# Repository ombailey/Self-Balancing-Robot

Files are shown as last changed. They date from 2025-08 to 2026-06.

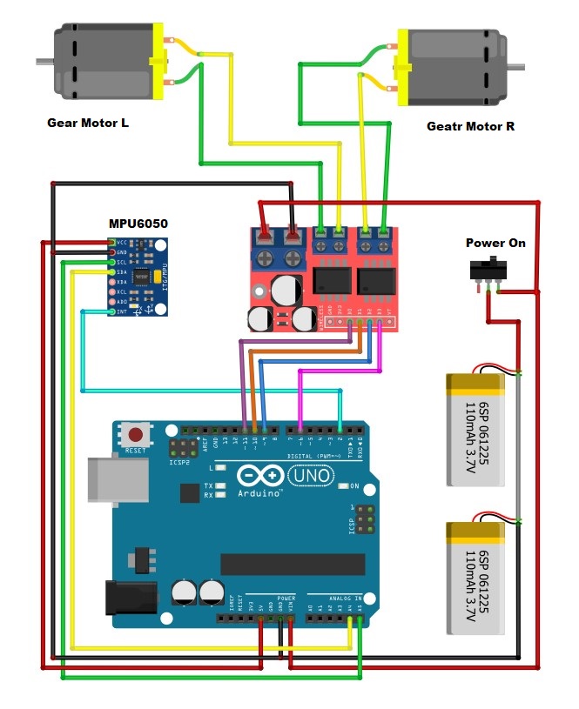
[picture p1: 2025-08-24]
Design/Schematic/0e4da654-2c3c-4273-9591-d0066f8ff958.jpg

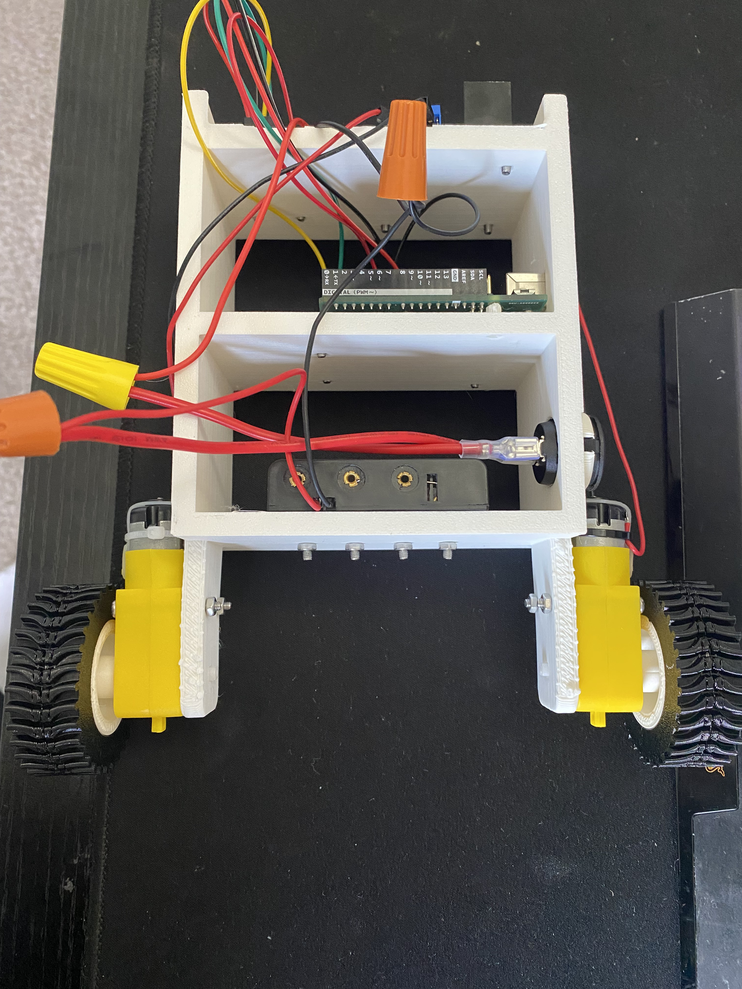
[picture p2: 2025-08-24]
Design/Schematic/SB robot pics/image1.jpeg

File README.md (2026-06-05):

# Self-Balancing Robot

## Overview
This project implements a two-wheeled self-balancing robot using a microcontroller, MPU6050 and PID control. The system models an inverted pendulum and applies state-space control methods to achieve upright stabilization on real hardware.

---

## Features
- Derived nonlinear equations of motion using Lagrangian mechanics
- Linearized state-space model about the upright equilibrium point
- Feedback controller design using pole placement
- Implementation on Arduino-based embedded system
- Complementary filter for real-time angle estimation
- Achieved sustained balancing on physical hardware (>60 seconds)

---

## Hardware
- Arduino microcontroller
- MPU6050
- DC motors
- L298N motor driver
- 3.7 Lithium Batteries (2)

---

## Software
- Embedded C++ (Arduino)
- Python
- Control Toolbox

---

## StatusPython
- Mathematical model derived and validated
- State-space controller designed and implemented
- Complementary filter implemented
- Successfully demonstrated stable balancing for 60+ seconds on repeated trials
- Ongoing improvements to robustness and performance

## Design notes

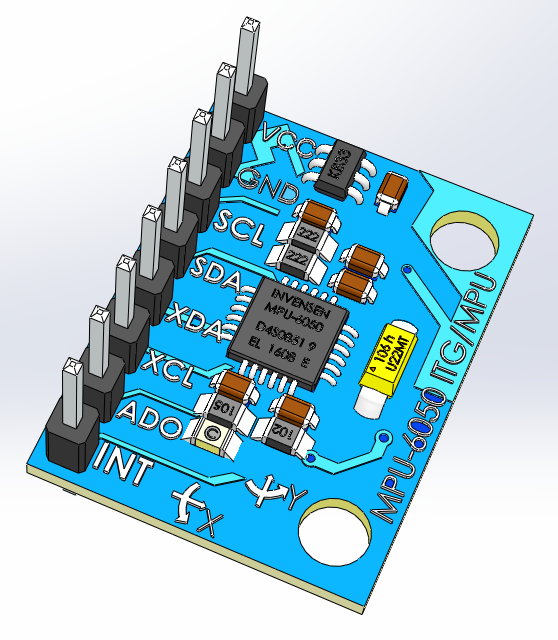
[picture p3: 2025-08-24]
Design/Grabcad/capteur-gyroscopique-analogique-accelerometre-3-axes-mpu-6050-1.snapshot.2/CaptureMPU2.PNG

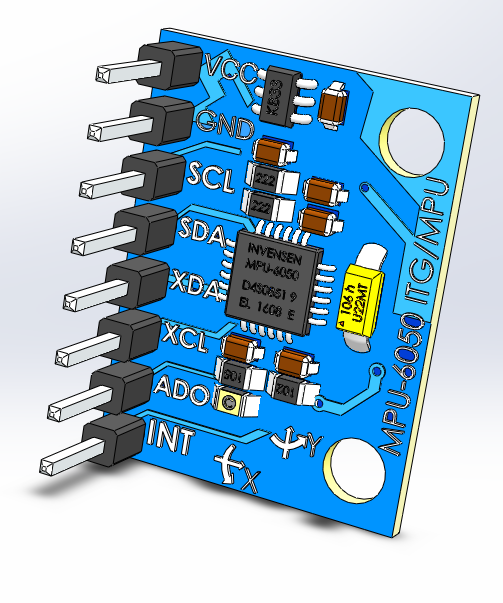
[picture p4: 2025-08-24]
Design/Grabcad/capteur-gyroscopique-analogique-accelerometre-3-axes-mpu-6050-1.snapshot.2/CaptureMPU1.PNG

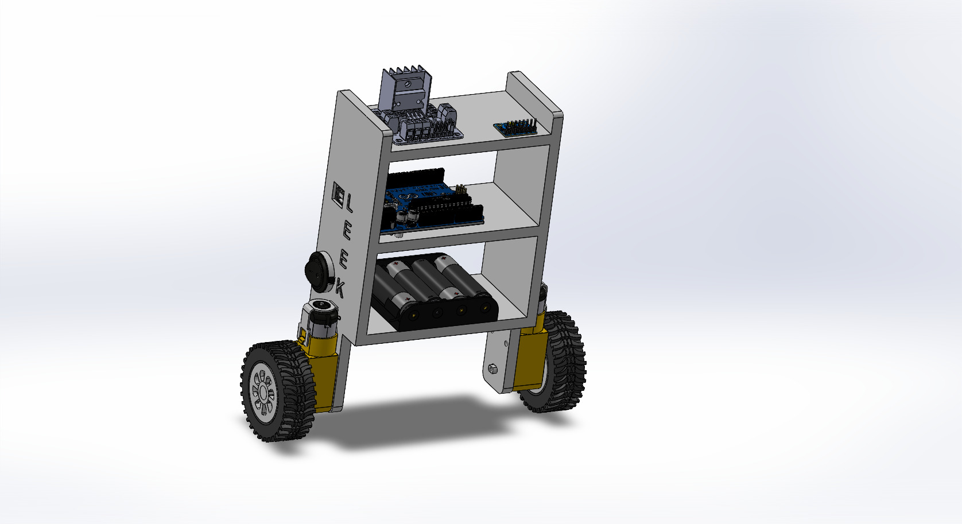
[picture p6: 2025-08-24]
Media/Screenshot3.JPG

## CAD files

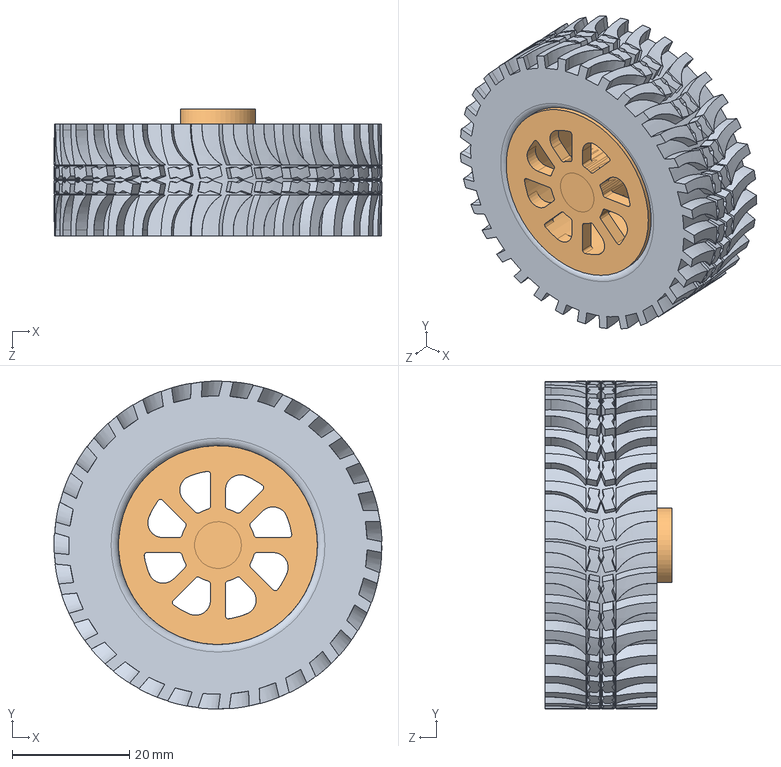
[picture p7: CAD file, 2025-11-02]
Design/CAD files/Big Tread Tire Assembly.SLDASM
55.9 x 55.9 x 21.6 mm
Rims3
Big Tread Tire

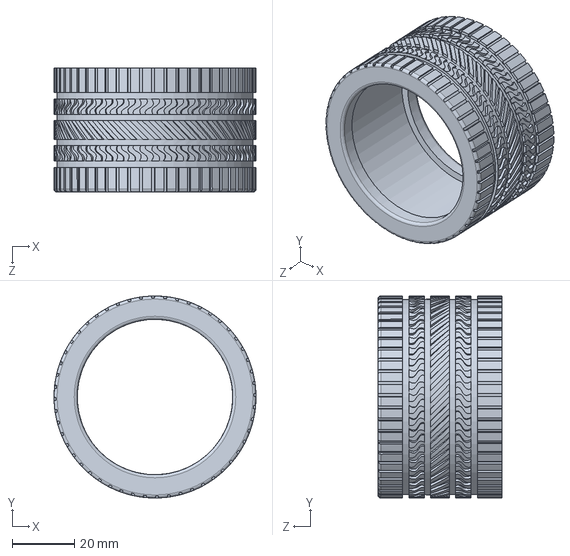
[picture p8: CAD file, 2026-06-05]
Design/CAD files/Tire.SLDPRT
65.0 x 65.0 x 40.0 mm

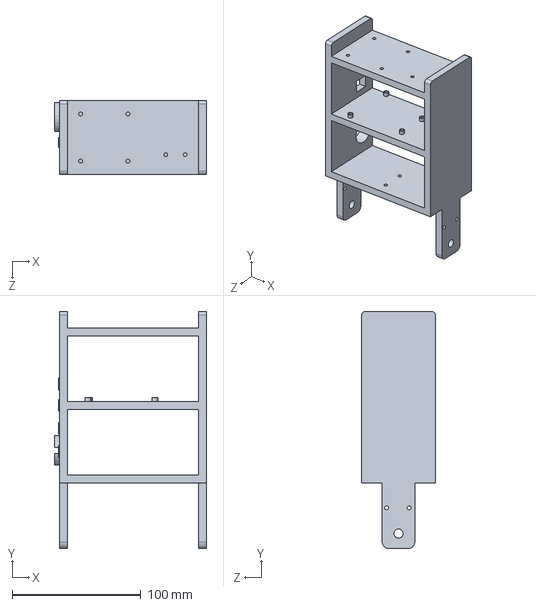
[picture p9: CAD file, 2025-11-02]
Design/frame2.SLDPRT
118.1 x 184.2 x 57.1 mm

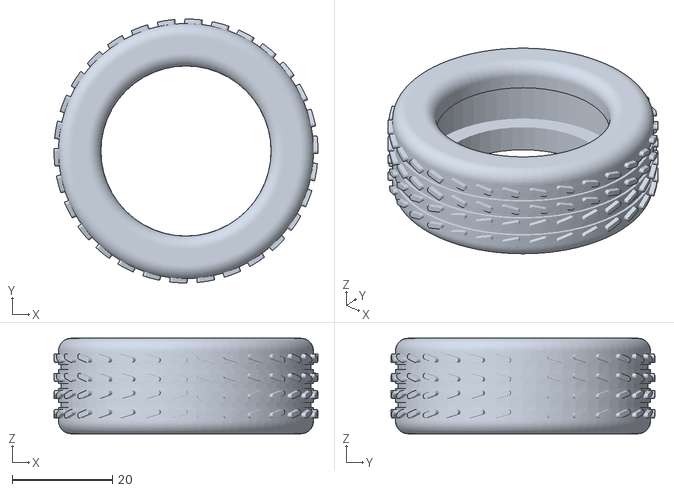
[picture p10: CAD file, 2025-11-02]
Design/STL Files/Tire3.STL
52.6 x 52.6 x 19.1

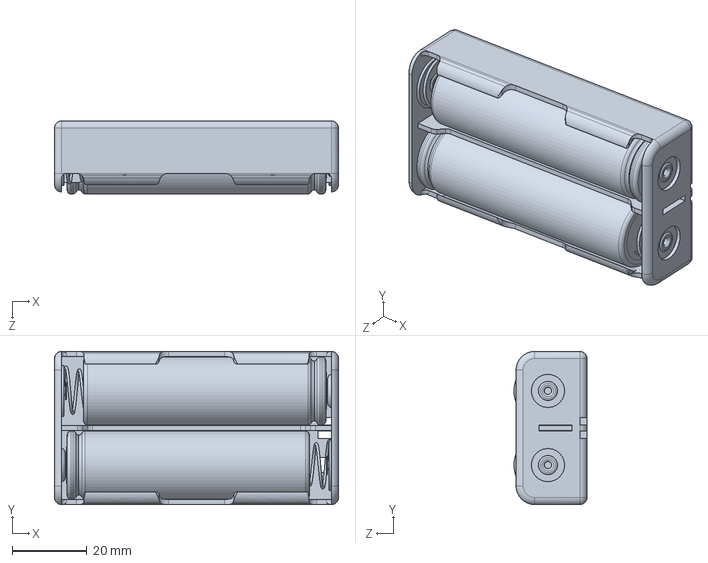
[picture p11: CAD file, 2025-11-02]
Design/BATTERY HOLDER x2 18650.SLDPRT
76.0 x 41.0 x 19.5 mm

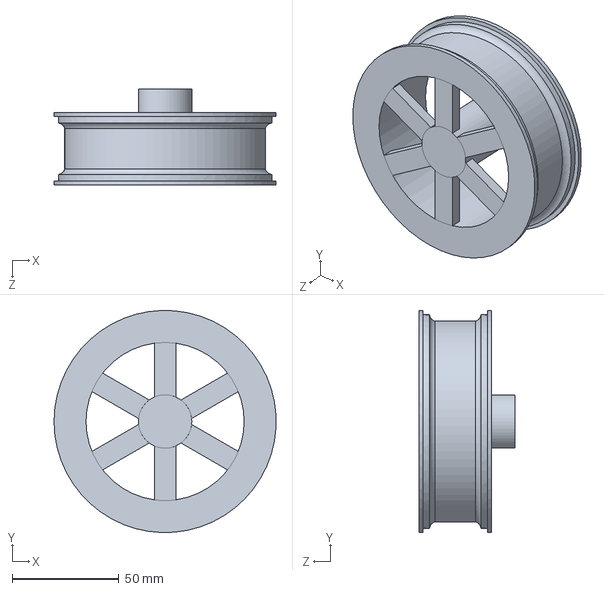
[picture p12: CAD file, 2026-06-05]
Design/CAD files/Rims.SLDPRT
103.9 x 104.0 x 45.0 mm

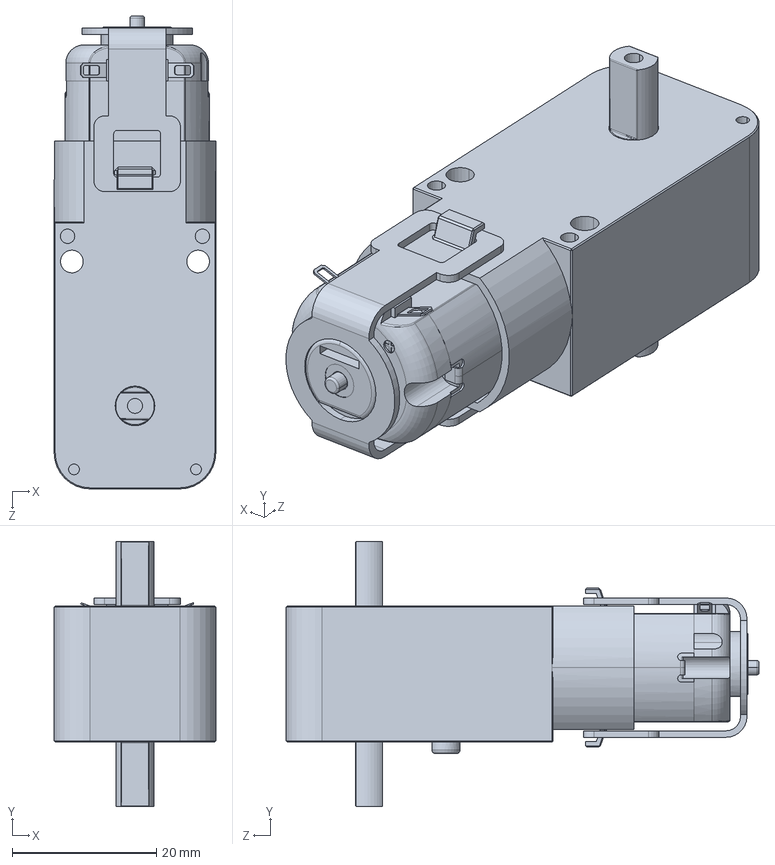
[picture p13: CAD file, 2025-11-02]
Design/CAD files/Mini Gear DC Motor 6 V Yellow.SLDPRT
22.4 x 36.7 x 65.5 mm

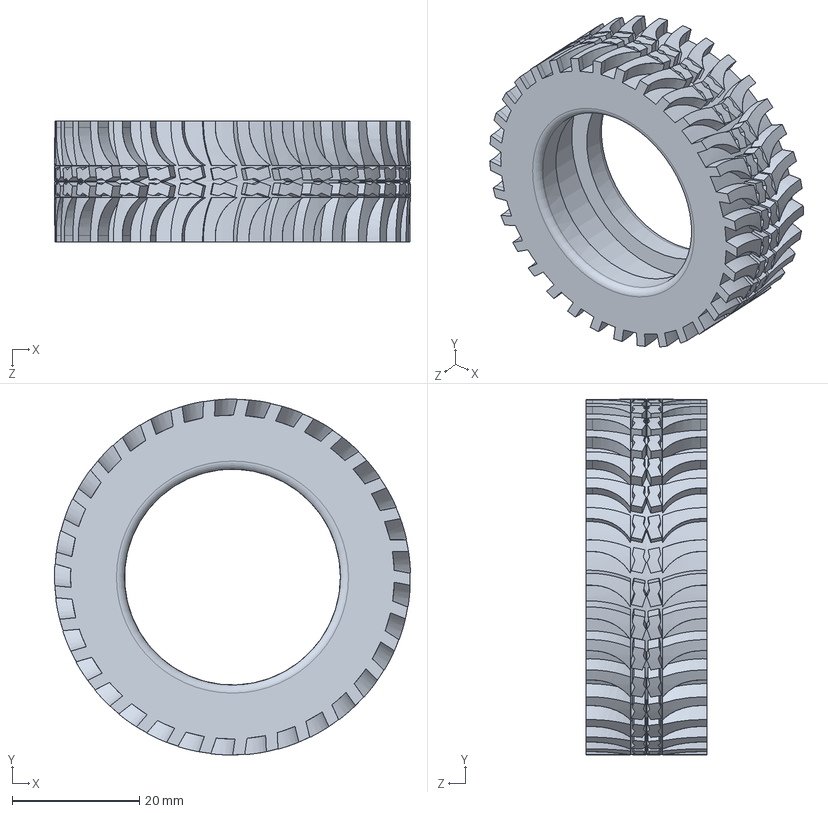
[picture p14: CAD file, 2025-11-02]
Design/CAD files/Big Tread Tire.SLDPRT
55.9 x 55.9 x 19.1 mm

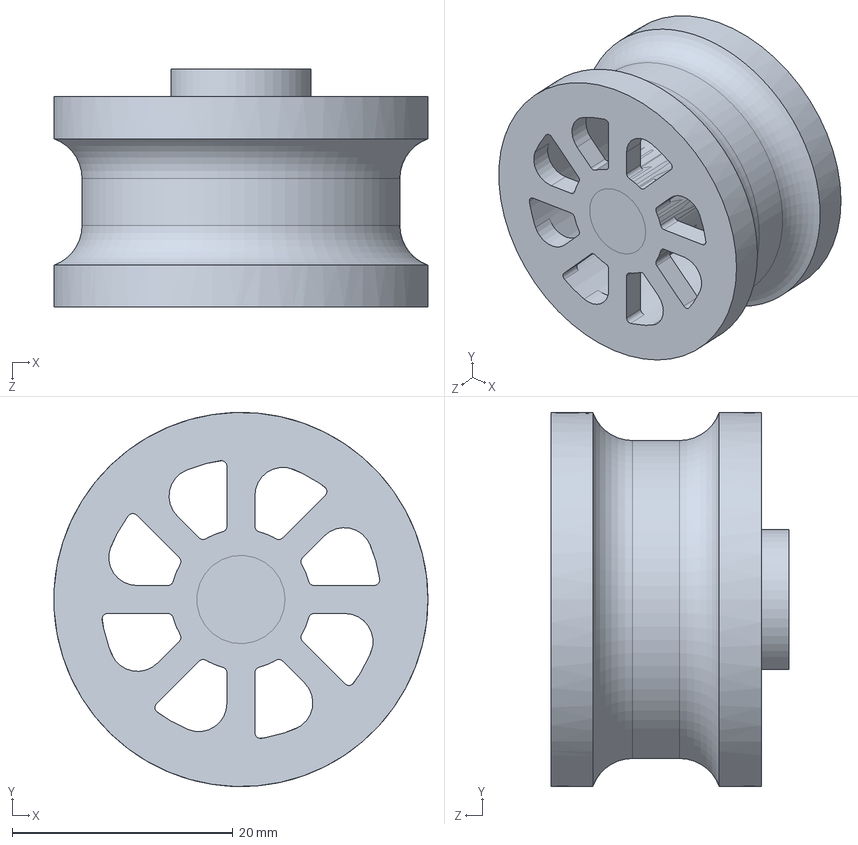
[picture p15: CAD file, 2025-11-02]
Design/CAD files/Rims3.SLDPRT
33.9 x 33.9 x 21.6 mm

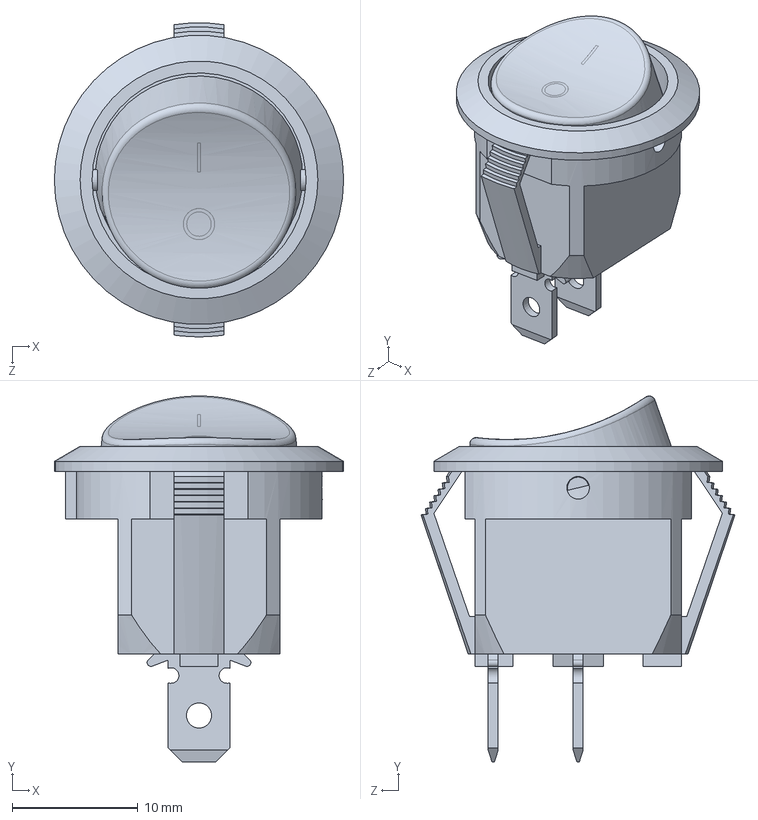
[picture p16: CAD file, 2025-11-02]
Design/CAD files/ROCKER_SWITCH.SLDPRT
23.0 x 29.1 x 25.0 mm

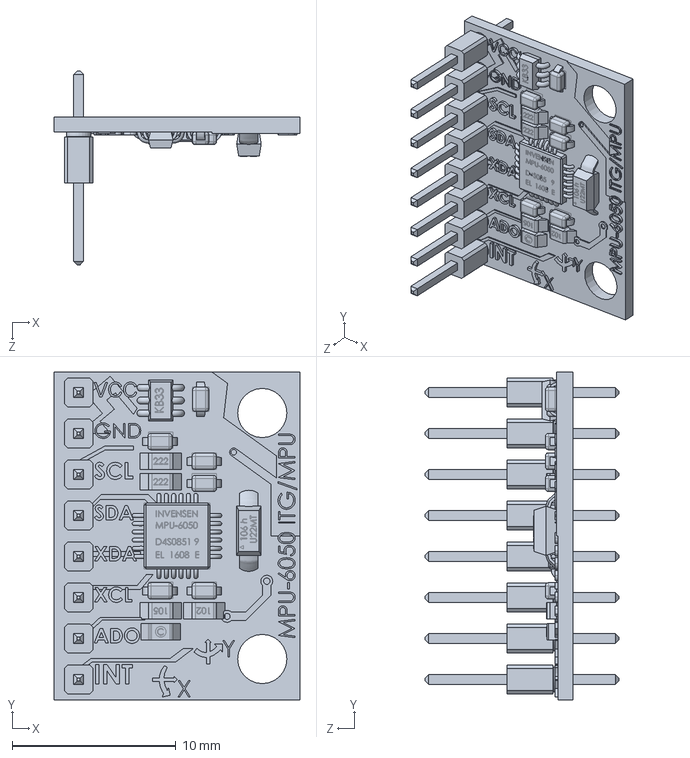
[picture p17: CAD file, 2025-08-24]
Design/CAD files/MPU-6050.SLDPRT
15.0 x 20.0 x 11.8 mm

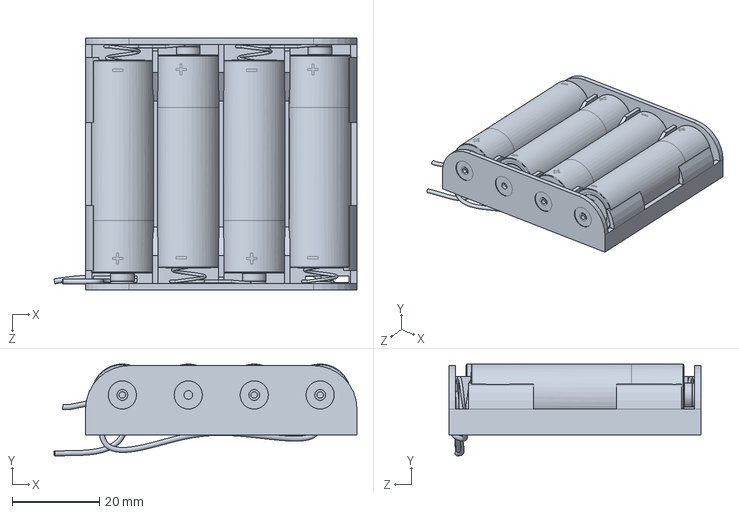
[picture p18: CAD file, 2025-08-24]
Design/CAD files/4x AA Alkaline 1.5 V Battery Pack.SLDPRT
69.6 x 21.1 x 58.0 mm

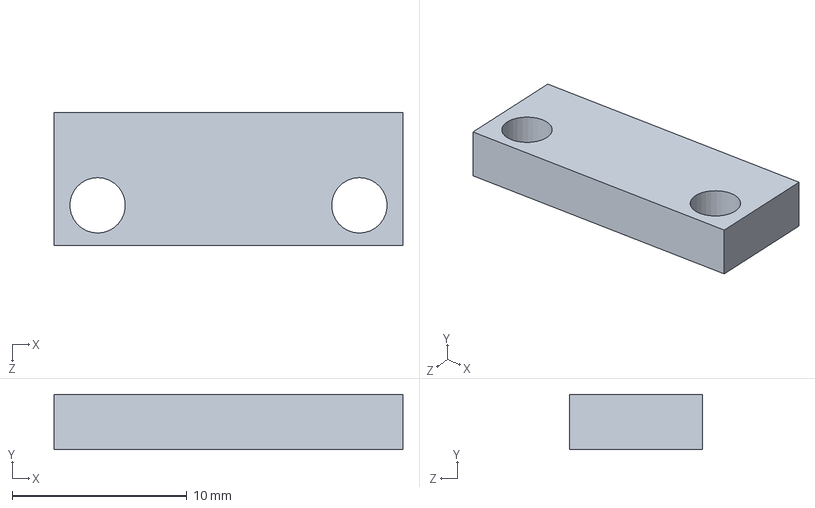
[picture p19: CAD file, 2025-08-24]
Design/CAD files/MPU Lifter.SLDPRT
20.0 x 3.17 x 7.62 mm

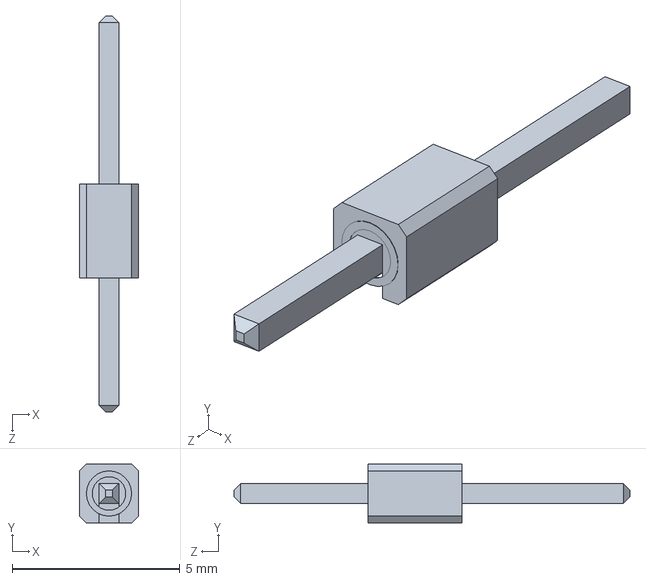
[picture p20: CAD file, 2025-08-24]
Design/Grabcad/capteur-gyroscopique-analogique-accelerometre-3-axes-mpu-6050-1.snapshot.2/MPU-6050/Connecteur de MPU-6050.SLDPRT
1.75 x 1.75 x 11.8 mm

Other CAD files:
Design/CAD files/Frame.SLDPRT
Design/Grabcad/capteur-gyroscopique-analogique-accelerometre-3-axes-mpu-6050-1.snapshot.2/MPU-6050/MPU-6050.SLDASM
Design/Grabcad/itg-mpu-gy-521-1.snapshot.16/ITG-MPU.STEP
Design/Grabcad/itg-mpu-gy-521-1.snapshot.16/Partes/Placa_Base.SLDPRT
Design/Frame.SLDPRT
Design/Grabcad/4x-aa-alkaline-1-5-v-battery-pack-1.snapshot.2/4x AA Alkaline 1.5 V Battery Pack.x_t
Design/Grabcad/capteur-gyroscopique-analogique-accelerometre-3-axes-mpu-6050-1.snapshot.2/MPU-6050/Capteur MPU6050.SLDPRT
Design/Grabcad/capteur-gyroscopique-analogique-accelerometre-3-axes-mpu-6050-1.snapshot.2/MPU-6050/Carte electronqie de MPU-6050.SLDPRT
Design/Grabcad/capteur-gyroscopique-analogique-accelerometre-3-axes-mpu-6050-1.snapshot.2/MPU-6050/Condensateur 1 de MPU-6050.SLDPRT
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

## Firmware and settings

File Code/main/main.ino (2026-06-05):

#include <Wire.h>

const int mpu = 0x68; //mpu I2C address
const float gyroLsbSens = 131; // LSB/degrees/second
const float accLsbSens = 16384; // LSB/g
const float g = 9.81; // m^2/s
const float alpha = 0.985;
const unsigned long loopPeriod = 2000; // 500 Hz
int16_t ax;
int16_t ay;
int16_t az;
int16_t gx;
int16_t gy;
int16_t gz;
float accelZ;
float gyDps;
int32_t gyBiasRaw = 0;
float gyBiasRawAvg;
float gyBias;
unsigned long prevTime = 0;
unsigned long nowTime;
float dt ;
float gyAngle = 0;
float compAngle = 0;
const float r2d = 180/PI;
const float d2r = PI/180;
// PID variables
float prevError = 0;
float integral = 0;
float derivative;
float setpoint = 1.90;
float output;
float error;
float kpScale = 6.5;
float kdScale = 4.15;
float kp = -13.41622596;
float kd = -0.95875022;
float ki = 0;
float pwm;
float prop;

// Creating motor functions
void Reverse(float pwm){
  PORTD = (1 << PD4) | (1 << PD7);
   pwm = abs(pwm);
  OCR2A = pwm;
  OCR1B = pwm;
};

void Forward(float pwm){
  PORTD = (1 << PD5) | (1 << PD6);
  OCR2A = pwm;
  OCR1B = pwm;
};

void Brake(){
  PORTD = ( 1 << PD4) | (1 << PD5) | (1 << PD6) | (1 << PD7);
  OCR2A = 0;
  OCR1B = 0;
}

float PolePlace(float setpoint, float currentAngle, float gyDps, float kp, float ki, float kd){
  error = setpoint - currentAngle;
  derivative = -gyDps;
  integral += error * dt;
  integral = constrain(integral,-50,50);
  output = -(kp*error*kpScale + ki*integral+ kd*derivative*kdScale);
  output = constrain(output,-255,255);
  prevError = error;
  return output;
};

void setup() {

  Wire.begin();
  Wire.setClock(400000);
  Serial.begin(115200);

  // Turning on MPU 6050
  Wire.beginTransmission(mpu);
  Wire.write(0x6B); // Power Management Register
  Wire.write(0);
  Wire.endTransmission(true);

  // Determine Gyroscope Y bias
  for (int i =0; i < 5000; i++){
    Wire.beginTransmission(mpu);
    Wire.write(0x45);
    Wire.endTransmission(false);
    Wire.requestFrom(mpu,2);
    int16_t gyRaw = Wire.read() << 8 | Wire.read();
    gyBiasRaw += gyRaw;
  };

  gyBiasRawAvg = gyBiasRaw / 5000.0;
  gyBias = gyBiasRawAvg/gyroLsbSens; 

  // Configuring Motors Pins
  DDRD |= (1 << PD4) | (1 << PD5) | (1 << PD6) | (1 << PD7); 
  DDRB |= (1 << PB2) | (1 << PB3);
  TCCR1A = (1 << COM1B1) | (1 << WGM10);
  TCCR1B = (1 << WGM12) | (1 << CS11);
  TCCR2A = (1 << COM2A1) | (1 << WGM20) | (1 << WGM21);
  TCCR2B = (1 << CS21);

  prevTime = micros();
};

void loop() {

  nowTime = micros();

  if (nowTime- prevTime < loopPeriod) {
    return;
    }
  
  prevTime += loopPeriod;
  dt = 0.002;

  // Creating bus with Gyroscope Y-Axis Register
  Wire.beginTransmission(mpu);
  Wire.write(0x3B); // Starting from AccelXOut register
  Wire.endTransmission(false);
  Wire.requestFrom(mpu,14);
  
  // Getting data from Accelerometer & Gyroscope
  ax = Wire.read() << 8 | Wire.read();
  ay = Wire.read() << 8 | Wire.read();
  az = Wire.read() << 8 | Wire.read();
  Wire.read(); Wire.read();
  gx = Wire.read() << 8 | Wire.read();
  gy = Wire.read() << 8 | Wire.read();
  gz = Wire.read() << 8 | Wire.read();

  // Calculating current angle of the robot
  float ax_g = ax/accLsbSens;
  float ay_g = ay/accLsbSens ;
  float az_g = az/accLsbSens ;
  gyDps = -(gy-gyBiasRawAvg)/gyroLsbSens;
  gyAngle += gyDps *dt;
  float angleBias = 4.00;

  // float pitch = (atan2(ax_g,sqrt((az_g*az_g) + (ay_g*ay_g))) * r2d) - angleBias;
  float pitch = (atan2(ax_g,sqrt((az_g*az_g) + (ay_g*ay_g))) * r2d);
  compAngle = alpha*(compAngle + (gyDps *dt)) + (1.0-alpha)*pitch;
  pwm = PolePlace(setpoint, compAngle, gyDps, kp, ki, kd);

  if (pwm > 0){
    Forward(pwm);  
  } else if (pwm < 0) {
    Reverse(pwm);
  } 
};

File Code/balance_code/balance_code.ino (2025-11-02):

#include "I2Cdev.h"
#include "MPU6050_6Axis_MotionApps20.h"
//#include "MPU6050_6Axis_MotionApps612.h" // Uncomment this library to work with DMP 6.12 and comment on the above library.
#include <PID_v1.h>
/* MPU6050 default I2C address is 0x68*/
MPU6050 mpu;
//MPU6050 mpu(0x69); //Use for AD0 high
//MPU6050 mpu(0x68, &Wire1); //Use for AD0 low, but 2nd Wire (TWI/I2C) object.

#define OUTPUT_READABLE_YAWPITCHROLL
//#define OUTPUT_READABLE_QUATERNION
//#define OUTPUT_READABLE_EULER
//#define OUTPUT_READABLE_REALACCEL
//#define OUTPUT_READABLE_WORLDACCEL
//#define OUTPUT_TEAPOT

int const INTERRUPT_PIN = 2;  // Define the interruption #0 pin
bool blinkState;

/*---MPU6050 Control/Status Variables---*/
bool DMPReady = false;  // Set true if DMP init was successful
uint8_t MPUIntStatus;   // Holds actual interrupt status byte from MPU
uint8_t devStatus;      // Return status after each device operation (0 = success, !0 = error)
uint16_t packetSize;    // Expected DMP packet size (default is 42 bytes)
uint8_t FIFOBuffer[64]; // FIFO storage buffer
uint16_t FIFOCount;

/*---Orientation/Motion Variables---*/ 
Quaternion q;           // [w, x, y, z]         Quaternion container
VectorInt16 aa;         // [x, y, z]            Accel sensor measurements
VectorInt16 gy;         // [x, y, z]            Gyro sensor measurements
VectorInt16 aaReal;     // [x, y, z]            Gravity-free accel sensor measurements
VectorInt16 aaWorld;    // [x, y, z]            World-frame accel sensor measurements
VectorFloat gravity;    // [x, y, z]            Gravity vector
float euler[3];         // [psi, theta, phi]    Euler angle container
float ypr[3];           // [yaw, pitch, roll]   Yaw/Pitch/Roll container and gravity vector
double input, output;
double setpoint = 180;
double Kp = 1;
double Ki = 10;
double Kd = 0.1;
float pitch;
const int IN1 = 5;
const int IN2 = 6;
const int IN3 = 9;
const int IN4 = 10;
const int ENA = 3;
const int ENB = 11;
PID myPid(&input, &output, &setpoint, Kp, Ki, Kd, DIRECT);

/*------Interrupt detection routine------*/
volatile bool MPUInterrupt = false;     // Indicates whether MPU6050 interrupt pin has gone high
void DMPDataReady() {
  MPUInterrupt = true;
}




void setup() {
  // #if I2CDEV_IMPLEMENTATION == I2CDEV_ARDUINO_WIRE
  //   Wire.begin();
  //   Wire.setClock(400000); // 400kHz I2C clock. Comment on this line if having compilation difficulties
  // #elif I2CDEV_IMPLEMENTATION == I2CDEV_BUILTIN_FASTWIRE
  //   Fastwire::setup(400, true);
  // #endif
  
  Serial.begin(115200); //115200 is required for Teapot Demo output
  mpu.initialize();
  devStatus = mpu.dmpInitialize();

  /* Supply your gyro offsets here, scaled for min sensitivity */
  mpu.setXAccelOffset(-1125); //Set your accelerometer offset for axis X
  mpu.setYAccelOffset(-1525); //Set your accelerometer offset for axis Y
  mpu.setZAccelOffset(645); //Set your accelerometer offset for axis Z
  mpu.setXGyroOffset(124);  //Set your gyro offset for axis X
  mpu.setYGyroOffset(37);  //Set your gyro offset for axis Y
  mpu.setZGyroOffset(21);  //Set your gyro offset for axis Z

  /* Making sure it worked (returns 0 if so) */ 
  if (devStatus == 0) {
    mpu.setDMPEnabled(true);
    attachInterrupt(digitalPinToInterrupt(INTERRUPT_PIN), DMPDataReady, RISING);
    MPUIntStatus = mpu.getIntStatus();
    DMPReady = true;
    packetSize = mpu.dmpGetFIFOPacketSize(); //Get expected DMP packet size for later comparison
    // Setup PID
    myPid.SetMode(AUTOMATIC);
    myPid.SetSampleTime(10);
    myPid.SetOutputLimits(-255, 255);
  } else
    {
        // ERROR!
        // 1 = initial memory load failed
        // 2 = DMP configuration updates failed
        // (if it's going to break, usually the code will be 1)
        Serial.print(F("DMP Initialization failed (code "));
        Serial.print(devStatus);
        Serial.println(F(")"));
    };

  //  Initializing Motor Pins

  pinMode(IN1, OUTPUT);
  pinMode(IN2, OUTPUT);
  pinMode(IN3, OUTPUT);
  pinMode(IN4, OUTPUT);

  // Turning off Motor Pins Initially

  digitalWrite(IN1, LOW);
  digitalWrite(IN2, LOW);
  digitalWrite(IN3, LOW);
  digitalWrite(IN4, LOW);
}

void loop() {
    if (!DMPReady) return;
  /* Read a packet from FIFO */
  while (!MPUInterrupt && FIFOCount < packetSize){
    myPid.Compute();
    Serial.print(input); Serial.print("=>"); Serial.print(output); Serial.print("\n");
  
    if (input > 120 && input < 220) {        // If the Bot is falling 
      if (output > 0) {                  // Falling towards front 
        Forward();                     // Rotate the wheels forward 
      } else if (output < 0) {           // Falling towards back
        Reverse();                     // Rotate the wheels backward 
      }
    } else {                               // If Bot not falling
      Stop();                            // Hold the wheels still
    };

    // Reset Interrupt flag and get INT_STATUS byte
    MPUInterrupt = false;
    MPUIntStatus = mpu.getIntStatus();
    FIFOCount = mpu.getFIFOCount();
    // Check for overflow
    if ((MPUIntStatus & 0x10) || FIFOCount == 1024){
      mpu.resetFIFO();
      Serial.print(("FIFO overflow!"));
    }
    else if (MPUIntStatus & 0x02){
      while (FIFOCount < packetSize) FIFOCount = mpu.getFIFOCount();
      mpu.getFIFOBytes(FIFOBuffer, packetSize);
      FIFOCount -= packetSize;
       /* Display Euler angles in degrees */
      mpu.dmpGetQuaternion(&q, FIFOBuffer);
      mpu.dmpGetGravity(&gravity, &q);
      mpu.dmpGetYawPitchRoll(ypr, &q, &gravity);
      input = ypr[1] * 180/M_PI + 180;
    }
  }
  /* Blink LED to indicate activity */
  blinkState = !blinkState;
  digitalWrite(LED_BUILTIN, blinkState);

  }

  void Forward() {
    // Motor A 
    digitalWrite(IN1, HIGH);
    digitalWrite(IN2, LOW);
    // Motor B 
    digitalWrite(IN3, HIGH);
    digitalWrite(IN4, LOW);
    Serial.println("Forward");
  }

  void Reverse() {
    // Motor A
    digitalWrite(IN1, LOW);
    digitalWrite(IN2, HIGH);
    // Motor B
    digitalWrite(IN3,LOW);
    digitalWrite(IN4, HIGH);
    Serial.println("Reverse");
  }

  void Stop(){
      // Motor A
    digitalWrite(IN1, LOW);
    digitalWrite(IN2, LOW);
    // Motor B
    digitalWrite(IN3,LOW);
    digitalWrite(IN4, LOW);
    Serial.println("Stop");
  }

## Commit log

2025-11-02 Updated Balance Code
    Balance code was updated and video file was added.
    [4x AA Alkaline 1.5 V Battery Pack.SLDPRT, BATTERY HOLDER x2 18650.SLDPRT, Big Tread Tire Assembly.SLDASM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]
2026-01-21 New Code
    Implemented serial communication and my formulated my own PID control algorithm.
2026-02-14 Fixed Code
    Cleaned up code and organized CAD files.
    [balance.ino, main.ino]
2026-06-05 Added control analysis file and updated controller on Arduino.
    [Rims.SLDPRT, Rims.STL, Tire.SLDPRT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]
